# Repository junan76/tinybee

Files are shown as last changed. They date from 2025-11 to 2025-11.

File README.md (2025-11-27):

# TINYBEE

This repository contains the hardware design of tinybeef405 flight controller, It supports the latest betaflight firmware currently, you can build your own firmware with the configuration files in the `configs` directory, see the details below.

I personally use this flight controller board as a hardware platform to learn betafight source code and stm32 microcontrollers, related videos were posted on my [Bilibili](https://space.bilibili.com/258537970) account.

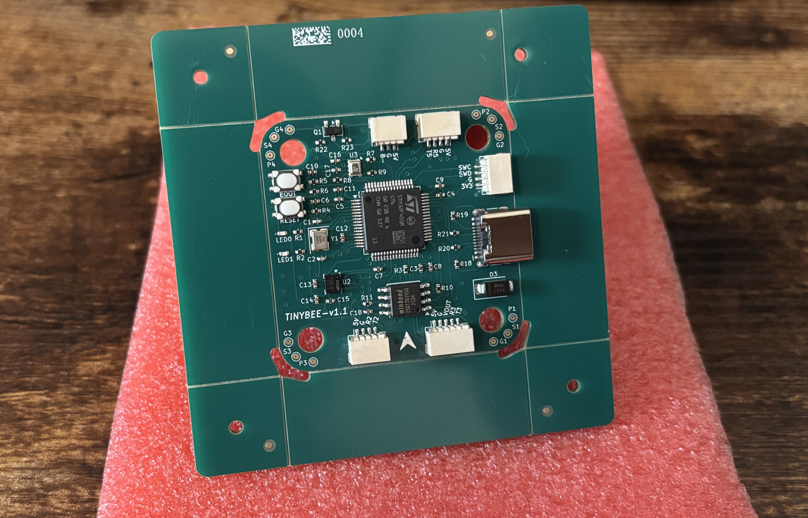
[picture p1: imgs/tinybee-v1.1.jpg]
tinybee-v1.1 pcb board


## Hardware and Features

- MCU: STM32F405
- IMU: ICM42688-P
- BARO: BMP280
- OSD: BetaFlight OSD, AT7456E
- Blackbox: 128MiB onboard flash, W25Q128JVSIQ
- UARTS: UART2/UART4/UART5
- SWD: Yes
- Digital VTX: Yes
- LEDs: LED0/LED1
- LED Strip: Yes
- Beeper: Yes
- Boot button: For easy entry into DFU mode

## Firmware build and flash

1. Get the latest betaflight source code

```shell
$ git clone https://github.com/betaflight/betaflight.git
$ cd betaflight
$ git submodule init && git submodule update --recursive
```

2. Copy config files

```shell
# download tinybee first, and then...
$ cp -r tinybee/configs/TNBF405 betaflight/src/config/configs
```

3. Build firmware

```shell
$ cd betaflight
$ make arm_sdk_install
$ make TNBF405
# wait until make completes its job, you will get:
$ ls obj
betaflight_2025.12.0-beta_STM32F405_TNBF405.hex  main
# "betaflight_2025.12.0-beta_STM32F405_TNBF405.hex" is what you need
```
4. Flash firmware

    - With [Betaflight Configurator](https://github.com/betaflight/betaflight-configurator/releases) properly installed and opened

    - Connect tinybee flight controlelr via usb

    - Enter DFU mode, press and hold the `BOOT` button, then press the `RESET` button

    - Go to the `Firmware Flasher` tab

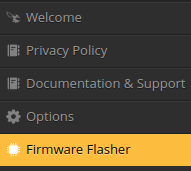
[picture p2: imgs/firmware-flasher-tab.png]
firmware flasher tab
        

    - Load local firmware then flash firmware

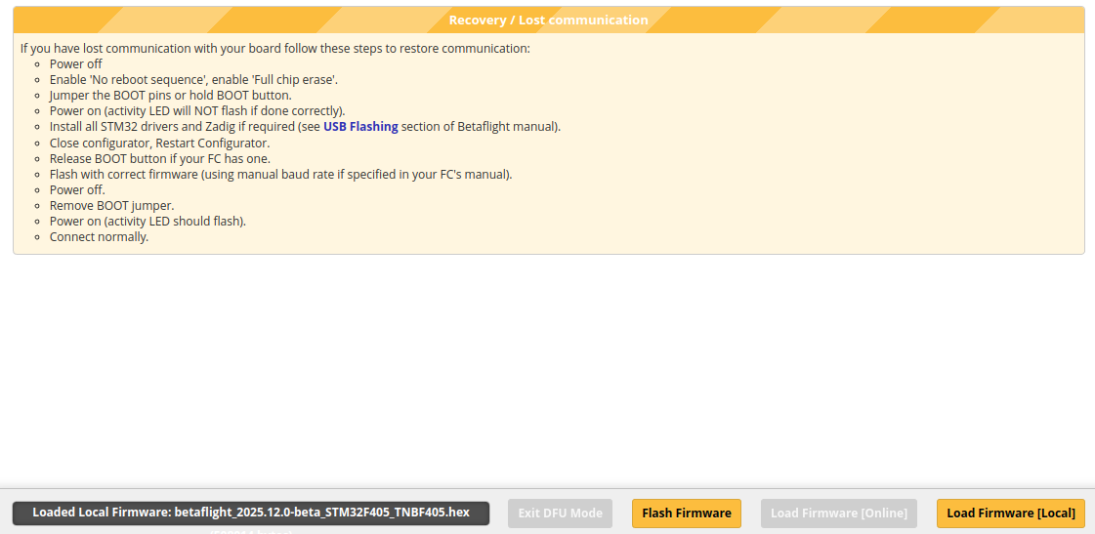
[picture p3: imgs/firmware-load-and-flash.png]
load local firmware and flash
        

5. Basic configurations

    You need to do at least the following setups so that your drone works.

    - `Ports`: select the right ports for RX and VTX
    - `Motors`: make sure the order and direction are both ok
    - `Modes`: how to arm your drone and switch to other modes
    - `VTX`: analog or digital
    - `OSD`: analog or digital

    For more information see [the betalfight wiki](https://www.betaflight.com/docs/wiki/getting-started/setup-guide).
    
    If everything goes well, the final result will be like this:

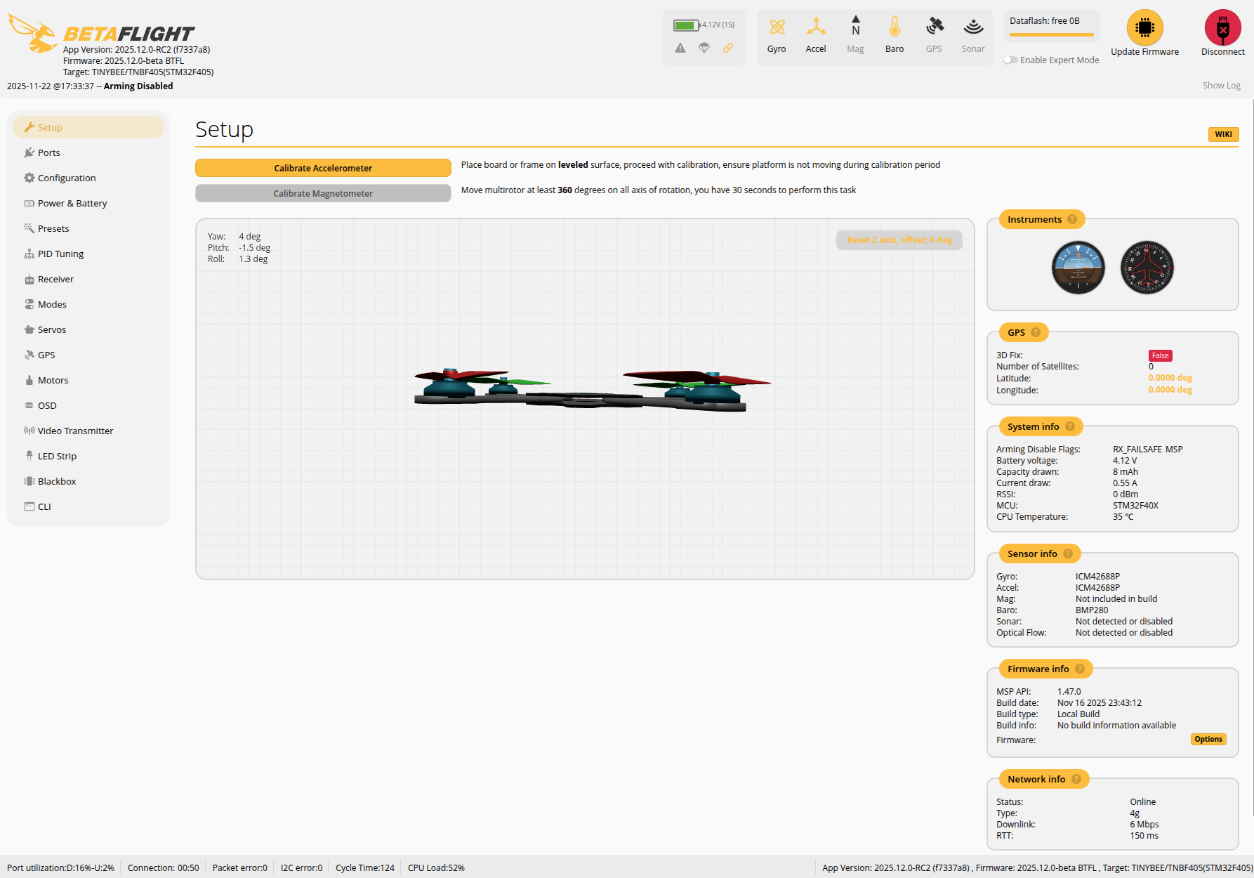
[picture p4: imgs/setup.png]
setup page
    

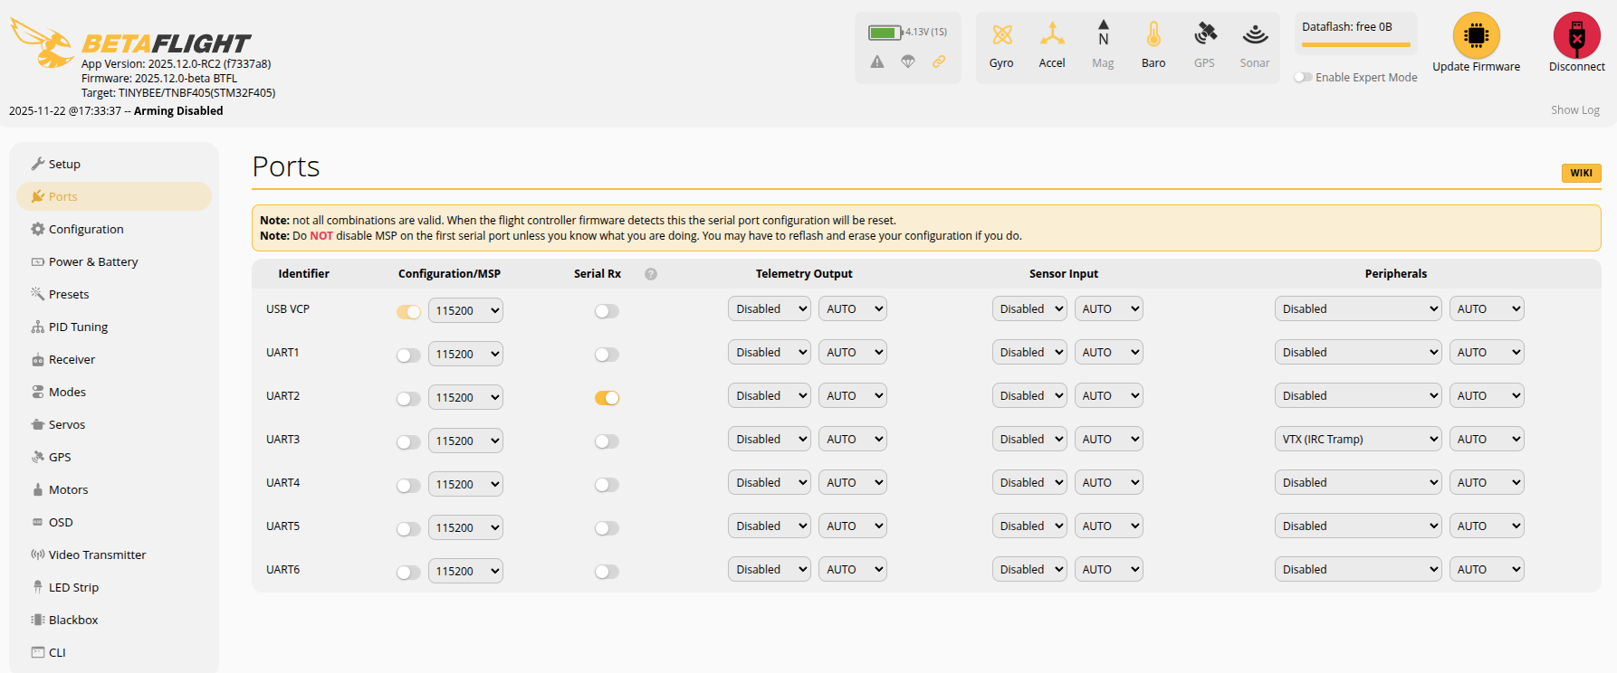
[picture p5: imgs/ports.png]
ports page
    

## Special Thanks

- [The original AcciF405 FC Design](https://oshwlab.com/jesuslg123/f4-v1)
- [Betaflight Project](https://www.betaflight.com/)

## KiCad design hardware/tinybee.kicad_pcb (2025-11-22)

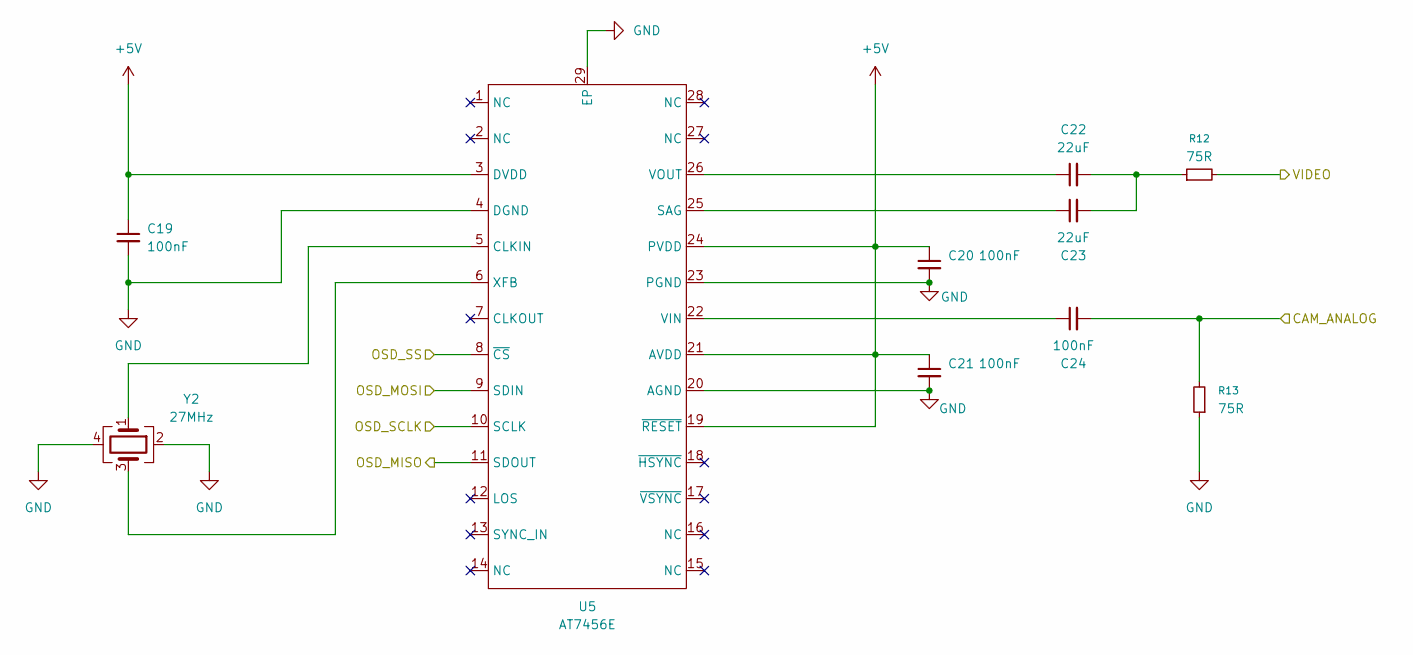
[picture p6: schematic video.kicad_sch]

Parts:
C19, C20, C21, C24: 100nF; C_0402_1005Metric; MPN C361198
C22, C23: 22uF; C_0603_1608Metric; MPN C2762594
R12, R13: 75R; R_0402_1005Metric; MPN C25133
U5: AT7456E; TSSOP-28-1EP_4.4x9.7mm_P0.65mm_EP2.85x6.7mm; MPN C82351
Y2: 27MHz; Crystal_SMD_3225-4Pin_3.2x2.5mm; MPN C9008

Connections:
+5V: C19.1, C20.1, C21.1, U5.3 (DVDD), U5.19 (~RESET), U5.21 (AVDD), U5.24 (PVDD); also elsewhere on the board
/CONNECTORS/CAM_ANALOG: C24.2, R13.2; also elsewhere on the board
/CONNECTORS/VIDEO: R12.2; also elsewhere on the board
/MCU/OSD_MISO: U5.11 (SDOUT); also elsewhere on the board
/MCU/OSD_MOSI: U5.9 (SDIN); also elsewhere on the board
/MCU/OSD_SCLK: U5.10 (SCLK); also elsewhere on the board
/MCU/OSD_SS: U5.8 (~CS); also elsewhere on the board
GND: C19.2, C20.2, C21.2, R13.1, U5.4 (DGND), U5.20 (AGND), U5.23 (PGND), U5.29 (EP), Y2.2, Y2.4; also elsewhere on the board
unnamed: C22.2, C23.2, R12.1
unnamed: U5.5 (CLKIN), Y2.1
unnamed: C23.1, U5.25 (SAG)
unnamed: C24.1, U5.22 (VIN)
unnamed: C22.1, U5.26 (VOUT)
unnamed: U5.6 (XFB), Y2.3

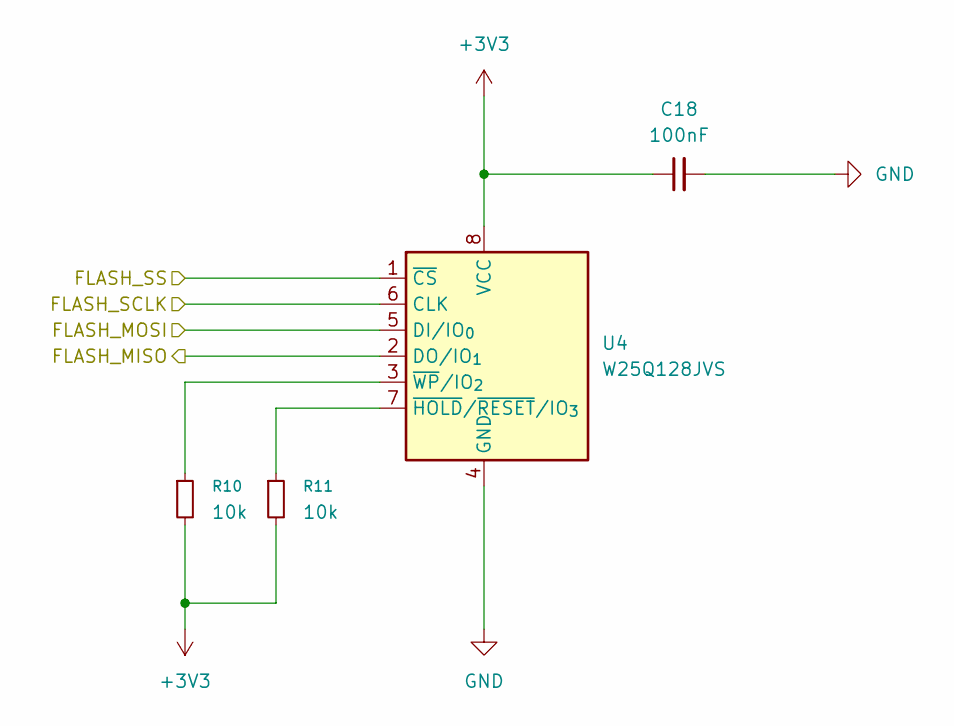
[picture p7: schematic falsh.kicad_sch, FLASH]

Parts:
C18: 100nF; C_0402_1005Metric; MPN C361198
R10, R11: 10k; R_0402_1005Metric; MPN C25744
U4: W25Q128JVS; SOIC-8_5.3x5.3mm_P1.27mm; MPN C113767

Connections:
+3V3: C18.1, R10.2, R11.2, U4.8 (VCC); also elsewhere on the board
/FLASH/FLASH_MISO: U4.2 (DO/IO_{1}); also elsewhere on the board
/FLASH/FLASH_MOSI: U4.5 (DI/IO_{0}); also elsewhere on the board
/FLASH/FLASH_SCLK: U4.6 (CLK); also elsewhere on the board
/FLASH/FLASH_SS: U4.1 (~CS); also elsewhere on the board
GND: C18.2, U4.4 (GND); also elsewhere on the board
unnamed: R11.1, U4.7 (~HOLD/~RESET/IO_{3})
unnamed: R10.1, U4.3 (~WP/IO_{2})

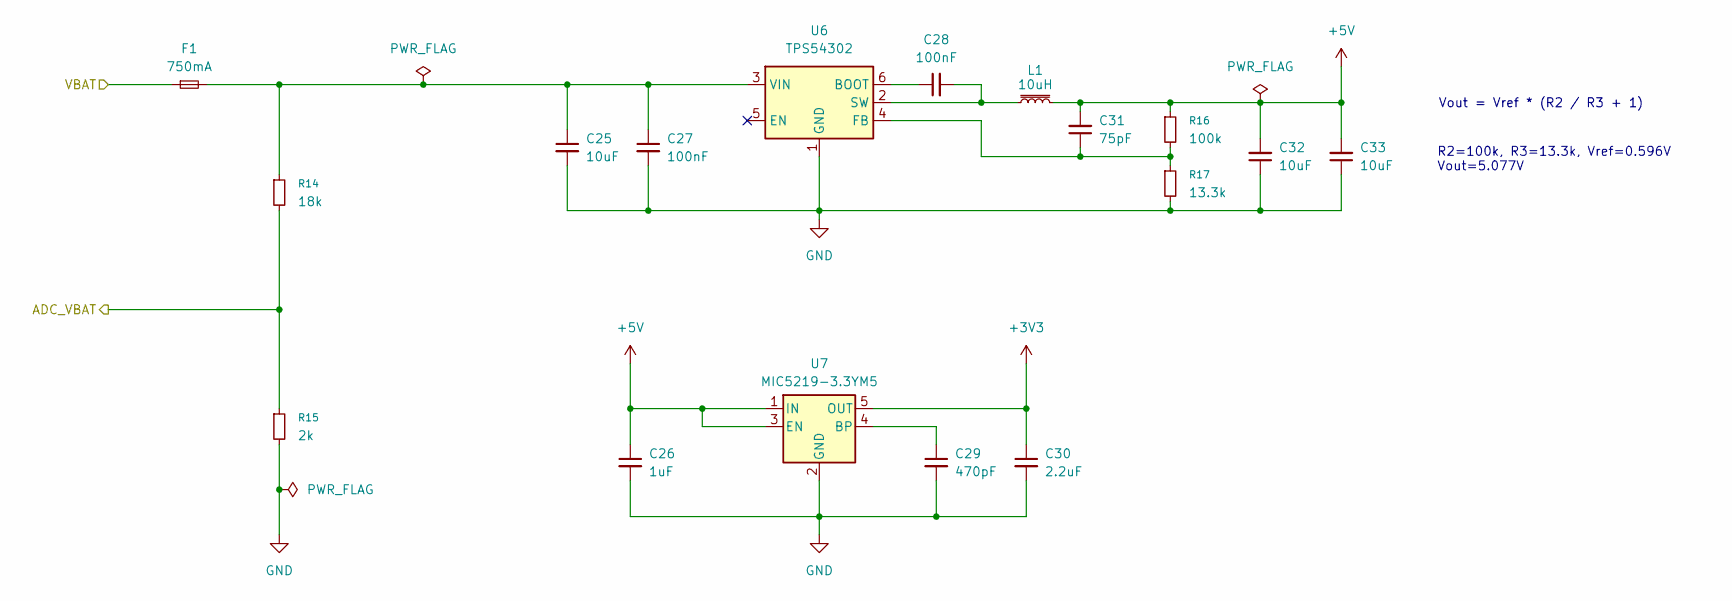
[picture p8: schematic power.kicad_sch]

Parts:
C25, C32, C33: 10uF; C_0402_1005Metric; MPN C7472949
C26: 1uF; C_0402_1005Metric; MPN C52923
C27, C28: 100nF; C_0402_1005Metric; MPN C361198
C29: 470pF; C_0402_1005Metric; MPN C1537
C30: 2.2uF; C_0402_1005Metric; MPN C76595
C31: 75pF; C_0402_1005Metric; MPN C107010
F1: 750mA; Fuse_1206_3216Metric; MPN C187594
L1: 10uH; L_Changjiang_FXL0630; MPN C167223
R14: 18k; R_0402_1005Metric; MPN C25762
R15: 2k; R_0402_1005Metric; MPN C4109
R16: 100k; R_0402_1005Metric; MPN C25741
R17: 13.3k; R_0402_1005Metric; MPN C122547
U6: TPS54302; SOT-23-6; MPN C311983
U7: MIC5219-3.3YM5; SOT-23-5; MPN C29613

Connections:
+3V3: C30.1, U7.5 (OUT); also elsewhere on the board
+5V: C26.1, C31.2, C32.2, C33.2, L1.2, R16.1, U7.1 (IN), U7.3 (EN); also elsewhere on the board
/CONNECTORS/VBAT: F1.1; also elsewhere on the board
/MCU/ADC_VBAT: R14.2, R15.1; also elsewhere on the board
GND: C25.2, C26.2, C27.2, C29.2, C30.2, C32.1, C33.1, R15.2, R17.2, U6.1 (GND), U7.2 (GND); also elsewhere on the board
unnamed: C28.1, U6.6 (BOOT)
unnamed: C31.1, R16.2, R17.1, U6.4 (FB)
unnamed: C28.2, L1.1, U6.2 (SW)
unnamed: C25.1, C27.1, F1.2, R14.1, U6.3 (VIN)
unnamed: C29.1, U7.4 (BP)

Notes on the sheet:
R2=100k, R3=13.3k, Vref=0.596V Vout=5.077V
Vout = Vref * (R2 / R3 + 1)

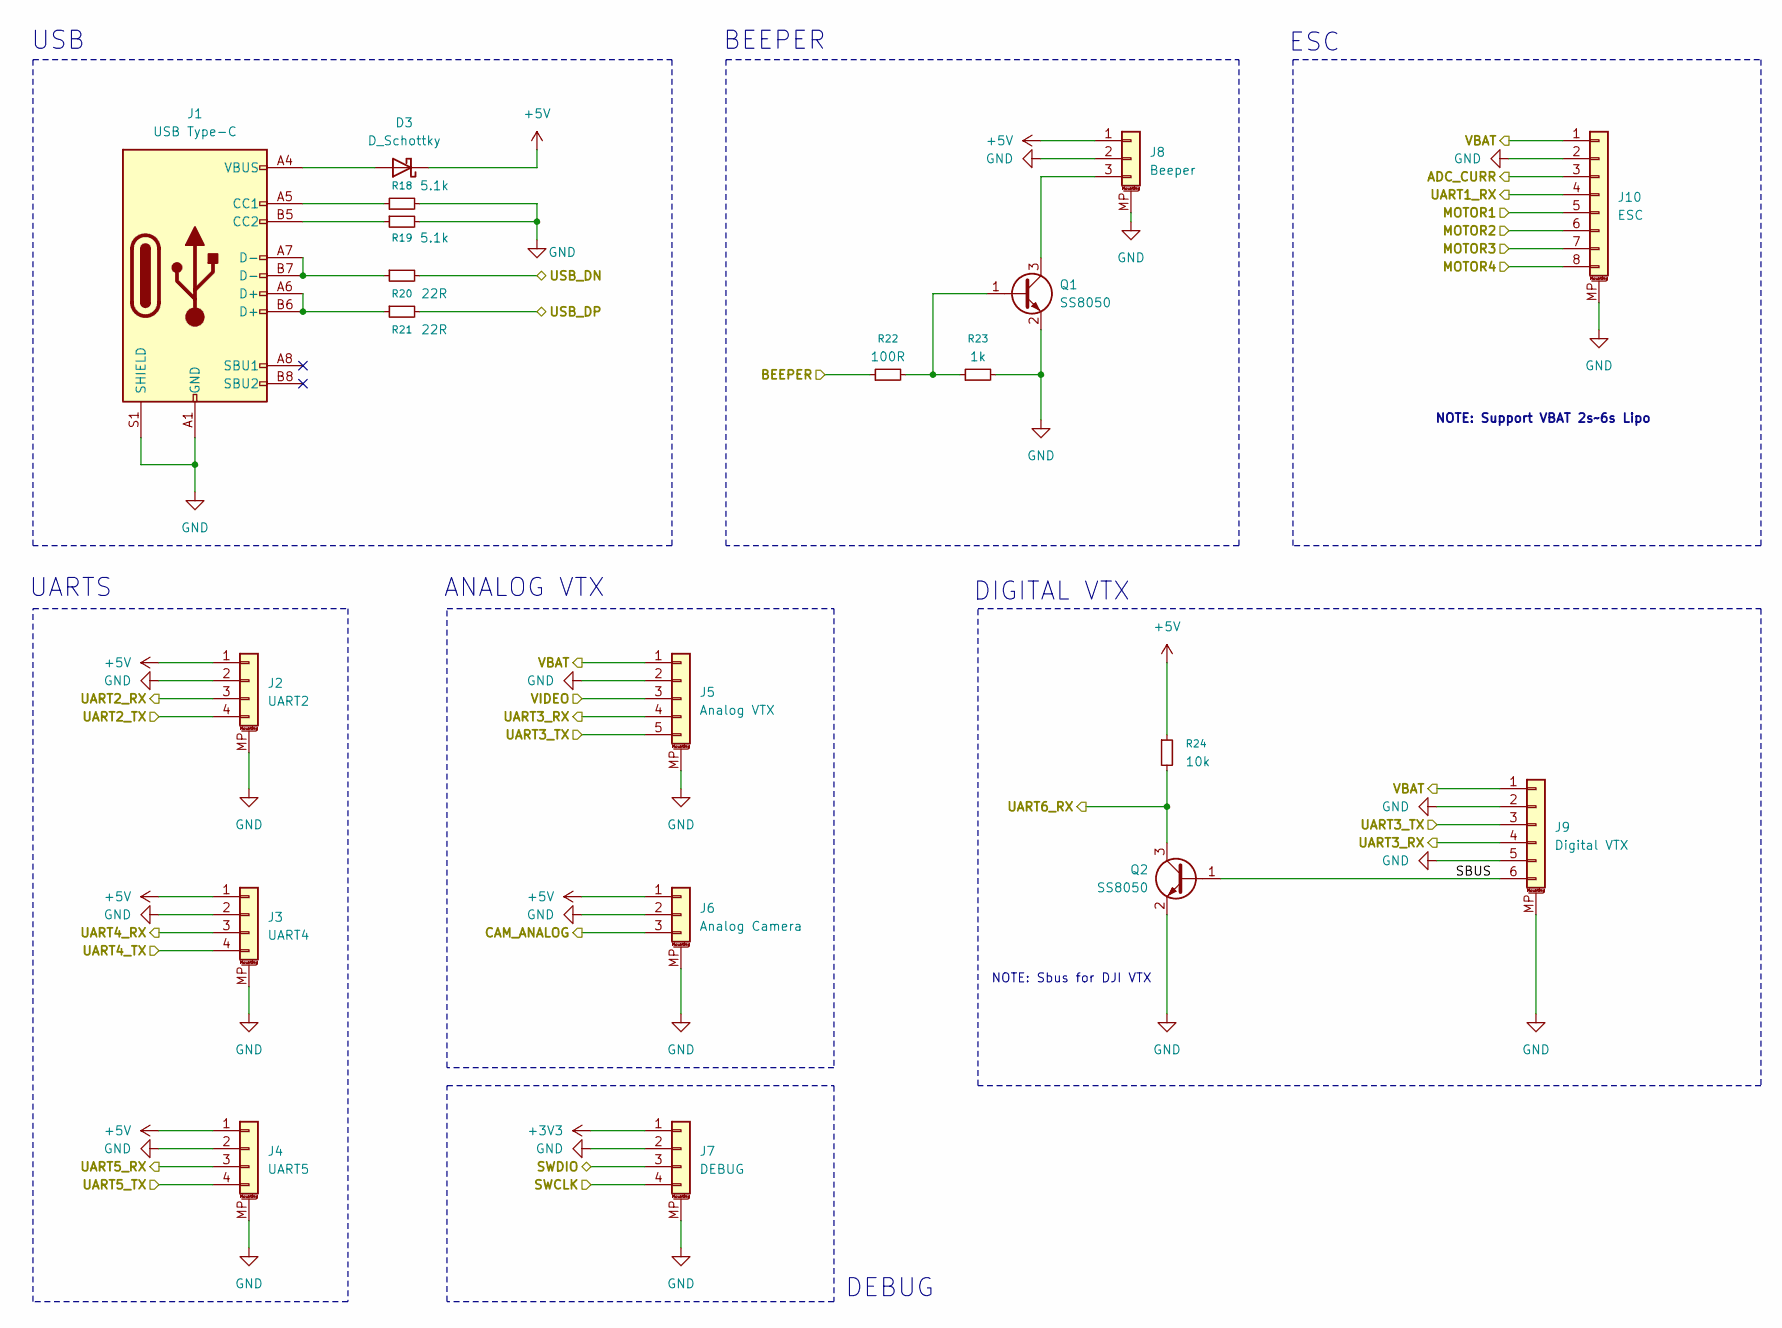
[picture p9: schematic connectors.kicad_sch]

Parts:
D3: D_Schottky; D_SMA; MPN C7420369
J1: USB Type-C; USB_C_Receptacle_HCTL_HC-TYPE-C-16P-01A; MPN C3148200
J2: UART2; JST_SH_SM04B-SRSS-TB_1x04-1MP_P1.00mm_Horizontal; MPN C3029343
J3: UART4; JST_SH_SM04B-SRSS-TB_1x04-1MP_P1.00mm_Horizontal; MPN C3029343
J4: UART5; JST_SH_SM04B-SRSS-TB_1x04-1MP_P1.00mm_Horizontal; MPN C3029343
J5: Analog VTX; JST_SH_SM05B-SRSS-TB_1x05-1MP_P1.00mm_Horizontal; MPN C3029344
J6: Analog Camera; JST_SH_SM03B-SRSS-TB_1x03-1MP_P1.00mm_Horizontal; MPN C3029342
J7: DEBUG; JST_SH_SM04B-SRSS-TB_1x04-1MP_P1.00mm_Horizontal; MPN C3029343
J8: Beeper; JST_SH_SM03B-SRSS-TB_1x03-1MP_P1.00mm_Horizontal; MPN C3029342
J9: Digital VTX; JST_SH_SM06B-SRSS-TB_1x06-1MP_P1.00mm_Horizontal; MPN C3029345
J10: ESC; JST_SH_SM08B-SRSS-TB_1x08-1MP_P1.00mm_Horizontal; MPN C3029347
Q1, Q2: SS8050; SOT-23; MPN C7420370
R18, R19: 5.1k; R_0402_1005Metric; MPN C25905
R20, R21: 22R; R_0402_1005Metric; MPN C25092
R22: 100R; R_0402_1005Metric; MPN C25076
R23: 1k; R_0402_1005Metric; MPN C11702
R24: 10k; R_0402_1005Metric; MPN C25744

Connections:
+3V3: J7.1; also elsewhere on the board
+5V: D3.1 (K), J2.1, J3.1, J4.1, J6.1, J8.1, R24.1; also elsewhere on the board
/CONNECTORS/ADC_CURR: J10.3; also elsewhere on the board
/CONNECTORS/BEEPER: R22.1; also elsewhere on the board
/CONNECTORS/CAM_ANALOG: J6.3; also elsewhere on the board
/CONNECTORS/MOTOR1: J10.5; also elsewhere on the board
/CONNECTORS/MOTOR2: J10.6; also elsewhere on the board
/CONNECTORS/MOTOR3: J10.7; also elsewhere on the board
/CONNECTORS/MOTOR4: J10.8; also elsewhere on the board
/CONNECTORS/SBUS: J9.6, Q2.1 (B)
/CONNECTORS/SWCLK: J7.4; also elsewhere on the board
/CONNECTORS/SWDIO: J7.3; also elsewhere on the board
/CONNECTORS/UART1_RX: J10.4; also elsewhere on the board
/CONNECTORS/UART2_RX: J2.3; also elsewhere on the board
/CONNECTORS/UART2_TX: J2.4; also elsewhere on the board
/CONNECTORS/UART3_RX: J5.4, J9.4; also elsewhere on the board
/CONNECTORS/UART3_TX: J5.5, J9.3; also elsewhere on the board
/CONNECTORS/UART4_RX: J3.3; also elsewhere on the board
/CONNECTORS/UART4_TX: J3.4; also elsewhere on the board
/CONNECTORS/UART5_RX: J4.3; also elsewhere on the board
/CONNECTORS/UART5_TX: J4.4; also elsewhere on the board
/CONNECTORS/UART6_RX: Q2.3 (C), R24.2; also elsewhere on the board
/CONNECTORS/USB_DN: R20.2; also elsewhere on the board
/CONNECTORS/USB_DP: R21.2; also elsewhere on the board
/CONNECTORS/VBAT: J5.1, J9.1, J10.1; also elsewhere on the board
/CONNECTORS/VIDEO: J5.3; also elsewhere on the board
GND: J1.A1 (GND), J1.A12 (GND), J1.B1 (GND), J1.B12 (GND), J1.S1 (SHIELD), J2.2, J2.MP (MountPin), J3.2, J3.MP (MountPin), J4.2, J4.MP (MountPin), J5.2, J5.MP (MountPin), J6.2, J6.MP (MountPin), J7.2, J7.MP (MountPin), J8.2, J8.MP (MountPin), J9.2, J9.5, J9.MP (MountPin), J10.2, J10.MP (MountPin), Q1.2 (E), Q2.2 (E), R18.2, R19.2, R23.2; also elsewhere on the board
unnamed: D3.2 (A), J1.A4 (VBUS), J1.A9 (VBUS), J1.B4 (VBUS), J1.B9 (VBUS)
unnamed: J1.A5 (CC1), R18.1
unnamed: J1.B5 (CC2), R19.1
unnamed: J1.A6 (D+), J1.B6 (D+), R21.1
unnamed: J1.A7 (D-), J1.B7 (D-), R20.1
unnamed: J8.3, Q1.3 (C)
unnamed: Q1.1 (B), R22.2, R23.1

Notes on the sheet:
ANALOG VTX
DEBUG
DIGITAL VTX
BEEPER
USB
ESC
UARTS
NOTE: Sbus for DJI VTX
NOTE: Support VBAT 2s~6s Lipo

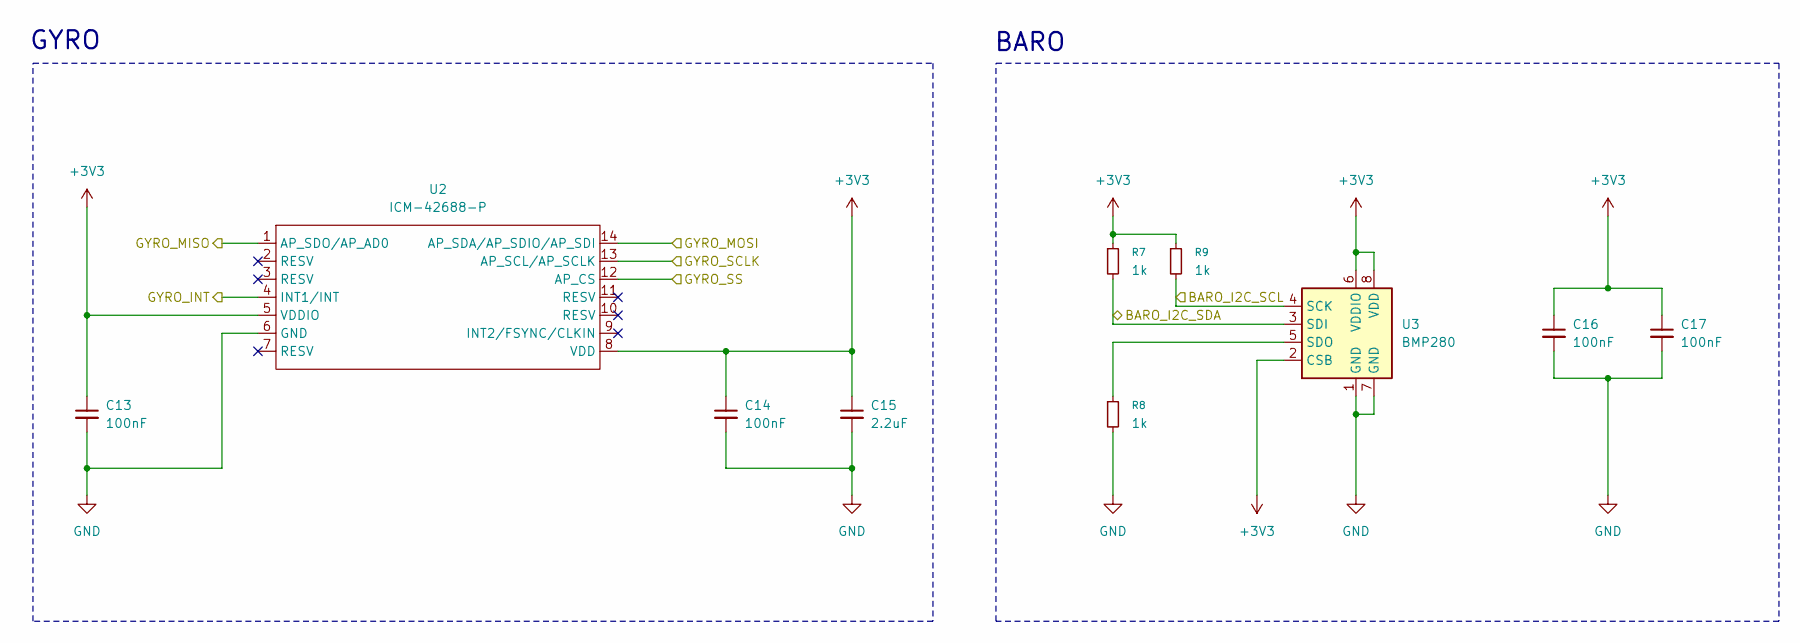
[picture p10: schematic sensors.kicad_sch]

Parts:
C13, C14, C16, C17: 100nF; C_0402_1005Metric; MPN C361198
C15: 2.2uF; C_0402_1005Metric; MPN C76595
R7, R8, R9: 1k; R_0402_1005Metric; MPN C11702
U2: ICM-42688-P; LGA-14_3x2.5mm_P0.5mm_LayoutBorder3x4y; MPN C1850418
U3: BMP280; Bosch_LGA-8_2x2.5mm_P0.65mm_ClockwisePinNumbering; MPN C83291

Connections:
+3V3: C13.1, C14.1, C15.1, C16.1, C17.1, R7.1, R9.1, U2.5 (VDDIO), U2.8 (VDD), U3.2 (CSB), U3.6 (VDDIO), U3.8 (VDD); also elsewhere on the board
/MCU/GYRO_INT: U2.4 (INT1/INT); also elsewhere on the board
/MCU/GYRO_MISO: U2.1 (AP_SDO/AP_AD0); also elsewhere on the board
/MCU/GYRO_MOSI: U2.14 (AP_SDA/AP_SDIO/AP_SDI); also elsewhere on the board
/MCU/GYRO_SCLK: U2.13 (AP_SCL/AP_SCLK); also elsewhere on the board
/MCU/GYRO_SS: U2.12 (AP_CS); also elsewhere on the board
/MCU/I2C1_SCL: R9.2, U3.4 (SCK); also elsewhere on the board
/MCU/I2C1_SDA: R7.2, U3.3 (SDI); also elsewhere on the board
GND: C13.2, C14.2, C15.2, C16.2, C17.2, R8.2, U2.6 (GND), U3.1 (GND), U3.7 (GND); also elsewhere on the board
unnamed: R8.1, U3.5 (SDO)

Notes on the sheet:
BARO
GYRO

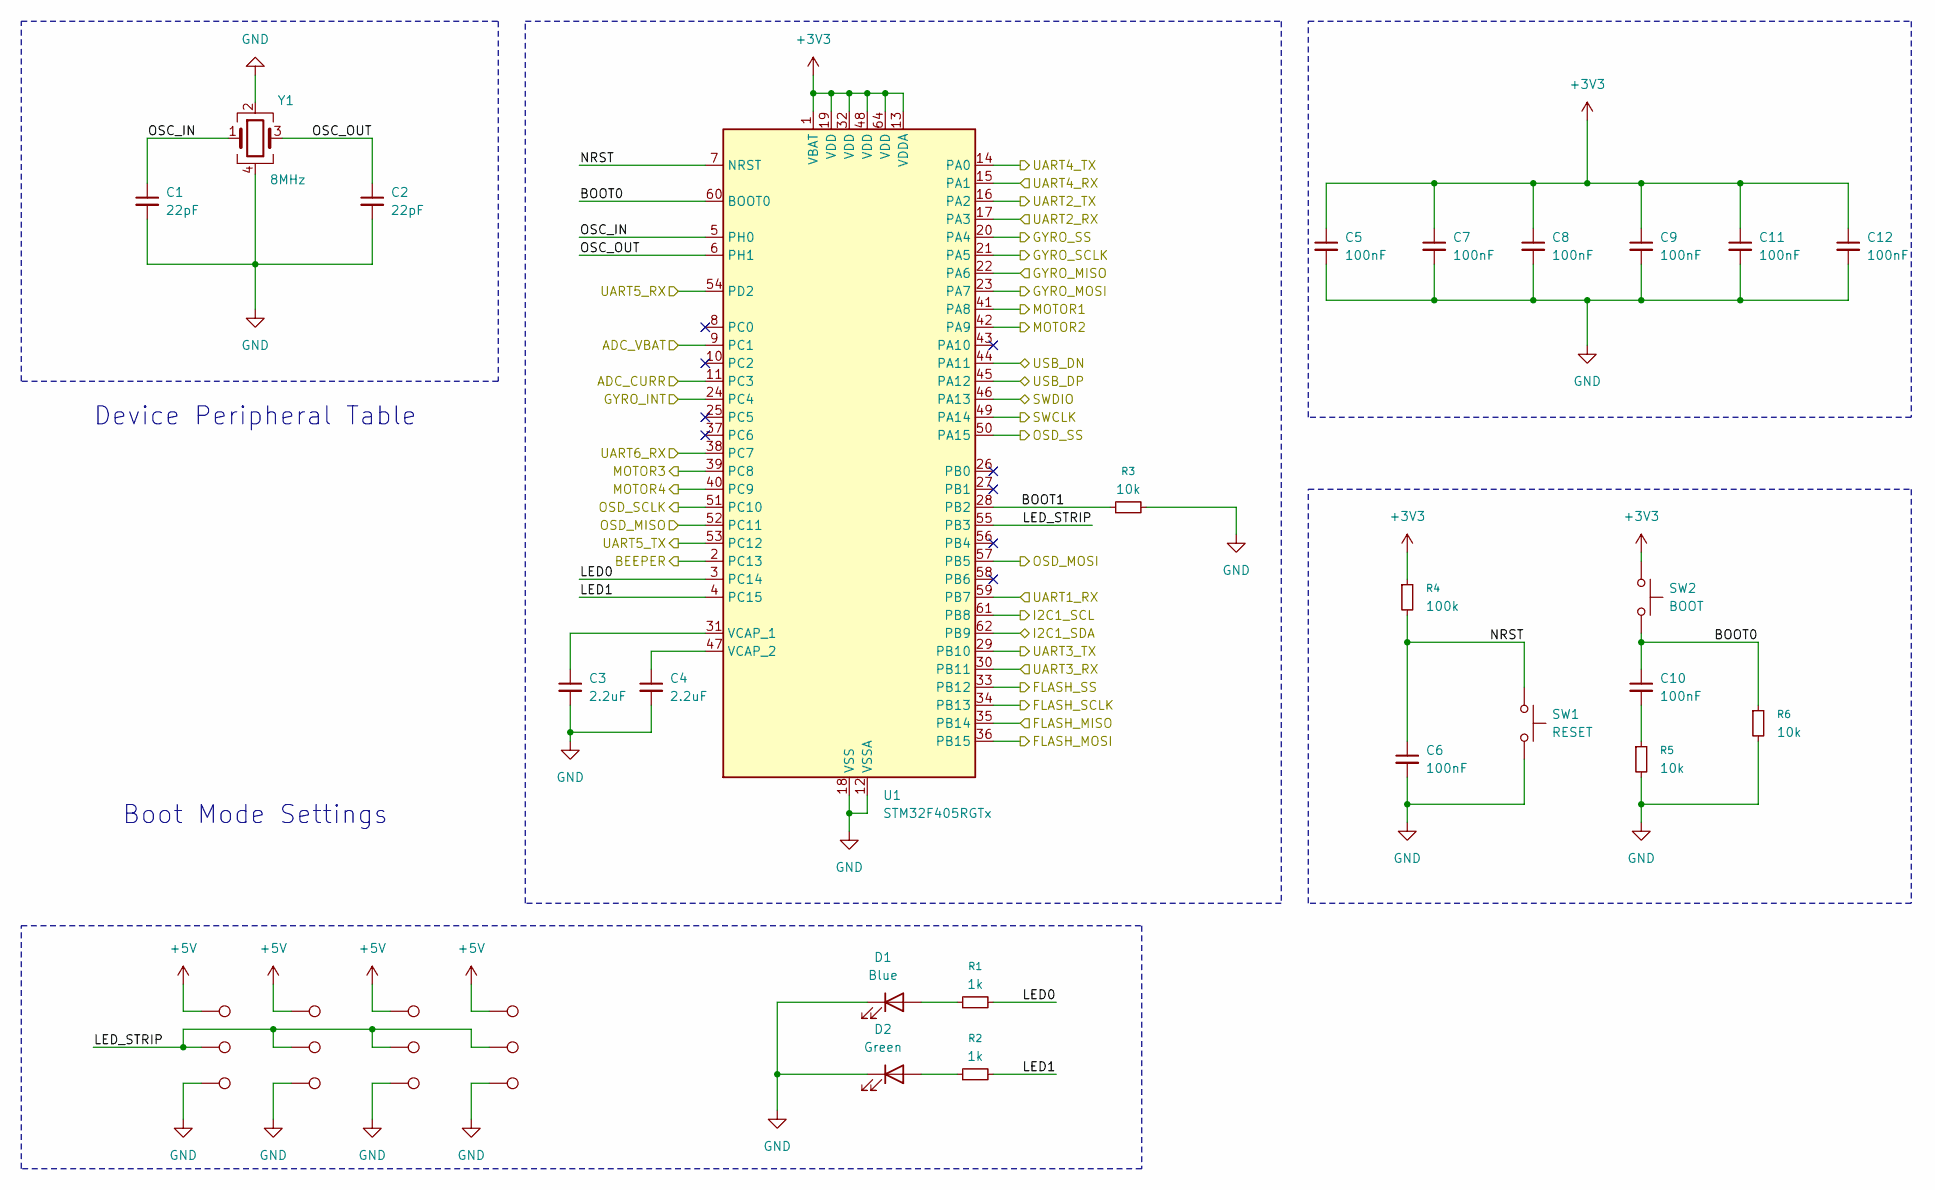
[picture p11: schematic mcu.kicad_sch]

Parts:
C1, C2: 22pF; C_0402_1005Metric; MPN C1555
C3, C4: 2.2uF; C_0402_1005Metric; MPN C76595
C5, C6, C7, C8, C9, C10, C11, C12: 100nF; C_0402_1005Metric; MPN C361198
D1: Blue; LED_0402_1005Metric; MPN C434447
D2: Green; LED_0402_1005Metric; MPN C434446
G1, G2, G3, G4: TestPoint; TestPoint_Pad_D1.0mm
P1, P2, P3, P4: TestPoint; TestPoint_Pad_D1.0mm
R1, R2: 1k; R_0402_1005Metric; MPN C11702
R3, R5, R6: 10k; R_0402_1005Metric; MPN C25744
R4: 100k; R_0402_1005Metric; MPN C25741
S1, S2, S3, S4: TestPoint; TestPoint_Pad_D1.0mm
SW1: RESET; TS3425BA; MPN C2681476
SW2: BOOT; TS3425BA; MPN C2681476
U1: STM32F405RGTx; LQFP-64_10x10mm_P0.5mm; MPN C15742
Y1: 8MHz; Crystal_SMD_3225-4Pin_3.2x2.5mm; MPN C2682775

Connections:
+3V3: C5.1, C7.1, C8.1, C9.1, C11.1, C12.1, R4.1, SW2.1, U1.1 (VBAT), U1.13 (VDDA), U1.19 (VDD), U1.32 (VDD), U1.48 (VDD), U1.64 (VDD); also elsewhere on the board
+5V: P1.1, P2.1, P3.1, P4.1; also elsewhere on the board
/CONNECTORS/ADC_CURR: U1.11 (PC3); also elsewhere on the board
/CONNECTORS/BEEPER: U1.2 (PC13); also elsewhere on the board
/CONNECTORS/MOTOR1: U1.41 (PA8); also elsewhere on the board
/CONNECTORS/MOTOR2: U1.42 (PA9); also elsewhere on the board
/CONNECTORS/MOTOR3: U1.39 (PC8); also elsewhere on the board
/CONNECTORS/MOTOR4: U1.40 (PC9); also elsewhere on the board
/CONNECTORS/SWCLK: U1.49 (PA14); also elsewhere on the board
/CONNECTORS/SWDIO: U1.46 (PA13); also elsewhere on the board
/CONNECTORS/UART1_RX: U1.59 (PB7); also elsewhere on the board
/CONNECTORS/UART2_RX: U1.17 (PA3); also elsewhere on the board
/CONNECTORS/UART2_TX: U1.16 (PA2); also elsewhere on the board
/CONNECTORS/UART3_RX: U1.30 (PB11); also elsewhere on the board
/CONNECTORS/UART3_TX: U1.29 (PB10); also elsewhere on the board
/CONNECTORS/UART4_RX: U1.15 (PA1); also elsewhere on the board
/CONNECTORS/UART4_TX: U1.14 (PA0); also elsewhere on the board
/CONNECTORS/UART5_RX: U1.54 (PD2); also elsewhere on the board
/CONNECTORS/UART5_TX: U1.53 (PC12); also elsewhere on the board
/CONNECTORS/UART6_RX: U1.38 (PC7); also elsewhere on the board
/CONNECTORS/USB_DN: U1.44 (PA11); also elsewhere on the board
/CONNECTORS/USB_DP: U1.45 (PA12); also elsewhere on the board
/FLASH/FLASH_MISO: U1.35 (PB14); also elsewhere on the board
/FLASH/FLASH_MOSI: U1.36 (PB15); also elsewhere on the board
/FLASH/FLASH_SCLK: U1.34 (PB13); also elsewhere on the board
/FLASH/FLASH_SS: U1.33 (PB12); also elsewhere on the board
/MCU/ADC_VBAT: U1.9 (PC1); also elsewhere on the board
/MCU/BOOT0: C10.1, R6.1, SW2.2, U1.60 (BOOT0)
/MCU/BOOT1: R3.1, U1.28 (PB2)
/MCU/GYRO_INT: U1.24 (PC4); also elsewhere on the board
/MCU/GYRO_MISO: U1.22 (PA6); also elsewhere on the board
/MCU/GYRO_MOSI: U1.23 (PA7); also elsewhere on the board
/MCU/GYRO_SCLK: U1.21 (PA5); also elsewhere on the board
/MCU/GYRO_SS: U1.20 (PA4); also elsewhere on the board
/MCU/I2C1_SCL: U1.61 (PB8); also elsewhere on the board
/MCU/I2C1_SDA: U1.62 (PB9); also elsewhere on the board
/MCU/LED0: R1.2, U1.3 (PC14)
/MCU/LED1: R2.2, U1.4 (PC15)
/MCU/LED_STRIP: S1.1, S2.1, S3.1, S4.1, U1.55 (PB3)
/MCU/NRST: C6.1, R4.2, SW1.1, U1.7 (NRST)
/MCU/OSC_IN: C1.1, U1.5 (PH0), Y1.1
/MCU/OSC_OUT: C2.1, U1.6 (PH1), Y1.3
/MCU/OSD_MISO: U1.52 (PC11); also elsewhere on the board
/MCU/OSD_MOSI: U1.57 (PB5); also elsewhere on the board
/MCU/OSD_SCLK: U1.51 (PC10); also elsewhere on the board
/MCU/OSD_SS: U1.50 (PA15); also elsewhere on the board
GND: C1.2, C2.2, C3.2, C4.2, C5.2, C6.2, C7.2, C8.2, C9.2, C11.2, C12.2, D1.1 (K), D2.1 (K), G1.1, G2.1, G3.1, G4.1, R3.2, R5.2, R6.2, SW1.2, U1.12 (VSSA), U1.18 (VSS), U1.63 (VSS), Y1.2, Y1.4; also elsewhere on the board
unnamed: C10.2, R5.1
unnamed: D1.2 (A), R1.1
unnamed: D2.2 (A), R2.1
unnamed: C3.1, U1.31 (VCAP_1)
unnamed: C4.1, U1.47 (VCAP_2)

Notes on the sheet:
Device Peripheral Table
Boot Mode Settings

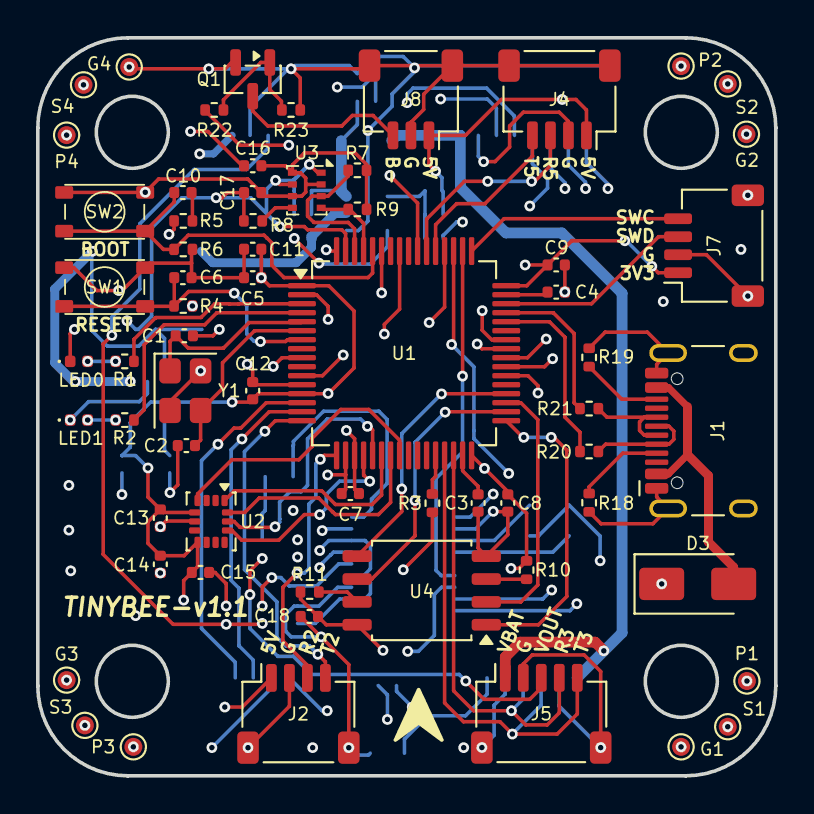
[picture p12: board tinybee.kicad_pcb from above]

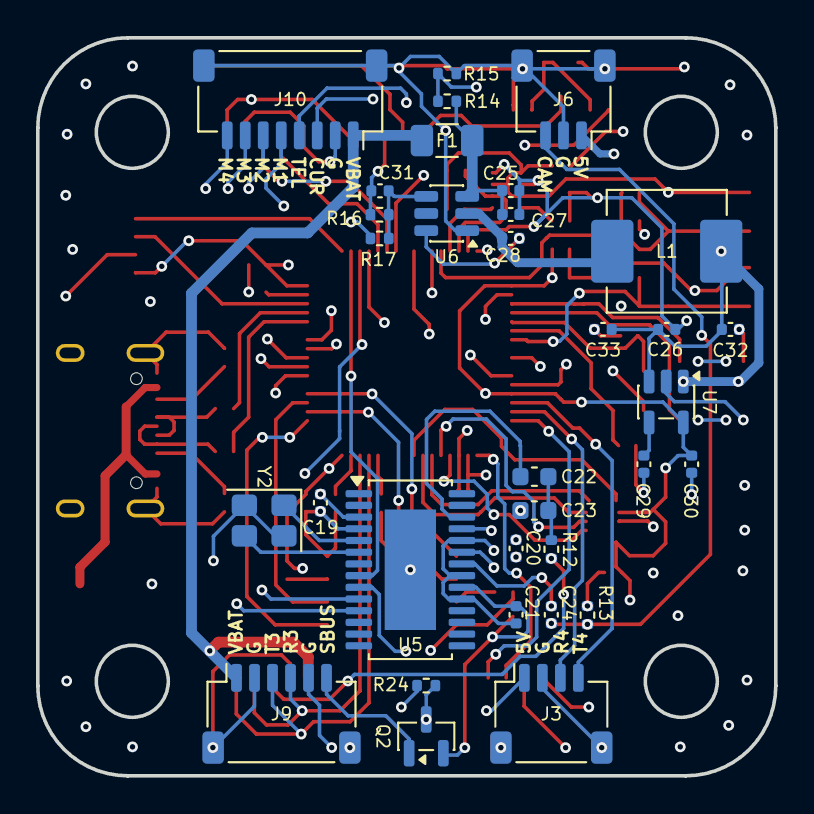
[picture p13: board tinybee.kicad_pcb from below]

Board: 4 copper layers, 41.0 x 41.0 mm, 97 parts (33 on the bottom side), 77 nets.

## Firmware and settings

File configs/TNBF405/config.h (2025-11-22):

/*
 * This file is part of Betaflight.
 *
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
 * See the GNU General Public License for more details.
 *
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
 * If not, see <http://www.gnu.org/licenses/>.
 */

#pragma once

#define FC_TARGET_MCU     STM32F405

#define BOARD_NAME        TNBF405
#define MANUFACTURER_ID   TINYBEE

#define USE_ACC
#define USE_GYRO

#define USE_ACC_SPI_ICM42688P // For ICM42688P variation
#define USE_GYRO_SPI_ICM42688P // For ICM42688P variation

#define USE_BARO
#define USE_BARO_BMP280

#define USE_FLASH
#define USE_FLASH_M25P16
#define USE_FLASH_W25Q128FV
#define USE_FLASH_W25N01G

#define USE_MAX7456

// I/O
#define LED0_PIN             PC14
#define LED1_PIN             PC15
#define BEEPER_PIN           PC13
#define BEEPER_INVERTED
#define LED_STRIP_PIN        PB3

// ACC/GYRO SPI 1
#define USE_SPI_GYRO
#define GYRO_1_EXTI_PIN      PC4
#define GYRO_1_CS_PIN        PA4
#define GYRO_1_SPI_INSTANCE  SPI1
#define GYRO_1_ALIGN CW180_DEG

#define SPI1_SCK_PIN         PA5
#define SPI1_SDI_PIN         PA6
#define SPI1_SDO_PIN         PA7

// FLASH SPI 2
#define SPI2_SCK_PIN         PB13
#define SPI2_SDI_PIN         PB14
#define SPI2_SDO_PIN         PB15

#define FLASH_CS_PIN         PB12
#define FLASH_SPI_INSTANCE   SPI2

// OSD SPI 3
#define SPI3_SCK_PIN         PC10
#define SPI3_SDI_PIN         PC11
#define SPI3_SDO_PIN         PB5

#define MAX7456_SPI_CS_PIN   PA15
#define MAX7456_SPI_INSTANCE SPI3

// ADC
#define USE_ADC
#define ADC_VBAT_PIN         PC1
#define ADC_CURR_PIN         PC3
#define ADC_INSTANCE         ADC1

// UART PORTS
#define UART1_TX_PIN         PB6
#define UART1_RX_PIN         PB7

#define UART2_TX_PIN         PA2
#define UART2_RX_PIN         PA3

#define UART3_TX_PIN         PB10
#define UART3_RX_PIN         PB11

#define UART4_TX_PIN         PA0
#define UART4_RX_PIN         PA1

#define UART5_TX_PIN         PC12
#define UART5_RX_PIN         PD2

#define UART6_TX_PIN         PC6
#define UART6_RX_PIN         PC7

// TIMERS
#define TIMER_PIN_MAPPING \
    TIMER_PIN_MAP( 0, PA8 , 1,  1) \
    TIMER_PIN_MAP( 1, PA9 , 1,  1) \
    TIMER_PIN_MAP( 2, PC8 , 1,  0) \
    TIMER_PIN_MAP( 3, PC9 , 1,  0) \
    TIMER_PIN_MAP( 4, PB3 , 1,  0)

// MOTORS PINOUT
#define MOTOR1_PIN           PA8
#define MOTOR2_PIN           PA9
#define MOTOR3_PIN           PC8
#define MOTOR4_PIN           PC9

#define ADC1_DMA_OPT         1

// BARO I2C
#define BARO_I2C_INSTANCE I2CDEV_1
#define MAG_I2C_INSTANCE I2CDEV_1

#define I2C1_SCL_PIN         PB8
#define I2C1_SDA_PIN         PB9

// DEFAULTS
#define DEFAULT_BLACKBOX_DEVICE         BLACKBOX_DEVICE_FLASH
#define DEFAULT_CURRENT_METER_SOURCE    CURRENT_METER_ADC
#define DEFAULT_VOLTAGE_METER_SOURCE    VOLTAGE_METER_ADC
#define DEFAULT_VOLTAGE_METER_SCALE     102
#define DEFAULT_DSHOT_BURST DSHOT_DMAR_OFF
#define DEFAULT_DSHOT_BITBANG DSHOT_BITBANG_OFF

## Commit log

2025-11-22 tinybee: hardware design and project introduction.
    [connectors.kicad_sch, falsh.kicad_sch, mcu.kicad_sch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]
2025-11-27 update readme, add final pcb image.

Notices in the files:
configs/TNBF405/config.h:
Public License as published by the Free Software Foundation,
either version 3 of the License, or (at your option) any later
